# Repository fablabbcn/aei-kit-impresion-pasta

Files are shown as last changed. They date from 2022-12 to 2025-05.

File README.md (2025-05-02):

# CLAB Paste and Biomaterials Printing Kit



Welcome to the repository for the [AEI-CLAB](https://fablabbcn.org/projects/clab) project. This deliverable from [Fab Lab Barcelona](https://fablabbcn.org/) contains the design files, assembly guides, schematics, and the Bill of Materials (BOM) required to modify a Creality Ender3 or similar FDM 3D printer into a paste extrusion system.

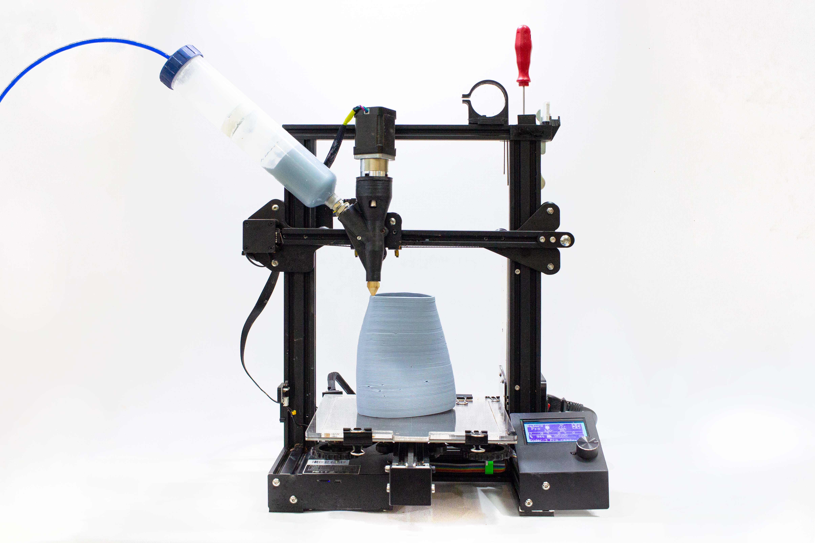
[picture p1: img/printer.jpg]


**Key Features:**

* Air pressure feed for extrusion: safer, easier to configure, and cleaner.
* Minimal hardware: only 4 screws needed for full disassembly, simplifying cleaning.
* Industrial-grade HDPE pressurised cartridges (200–300 cc), rated up to 6.9 bar (typical working pressure: 3–4 bar).
* Custom stainless-steel extruder screws with anti-corrosion plating.
* Silent air compressor (\~55 dB), 6 bar range, 3L tank with regulation and safety release valves.
  
## 3D-Printed Version

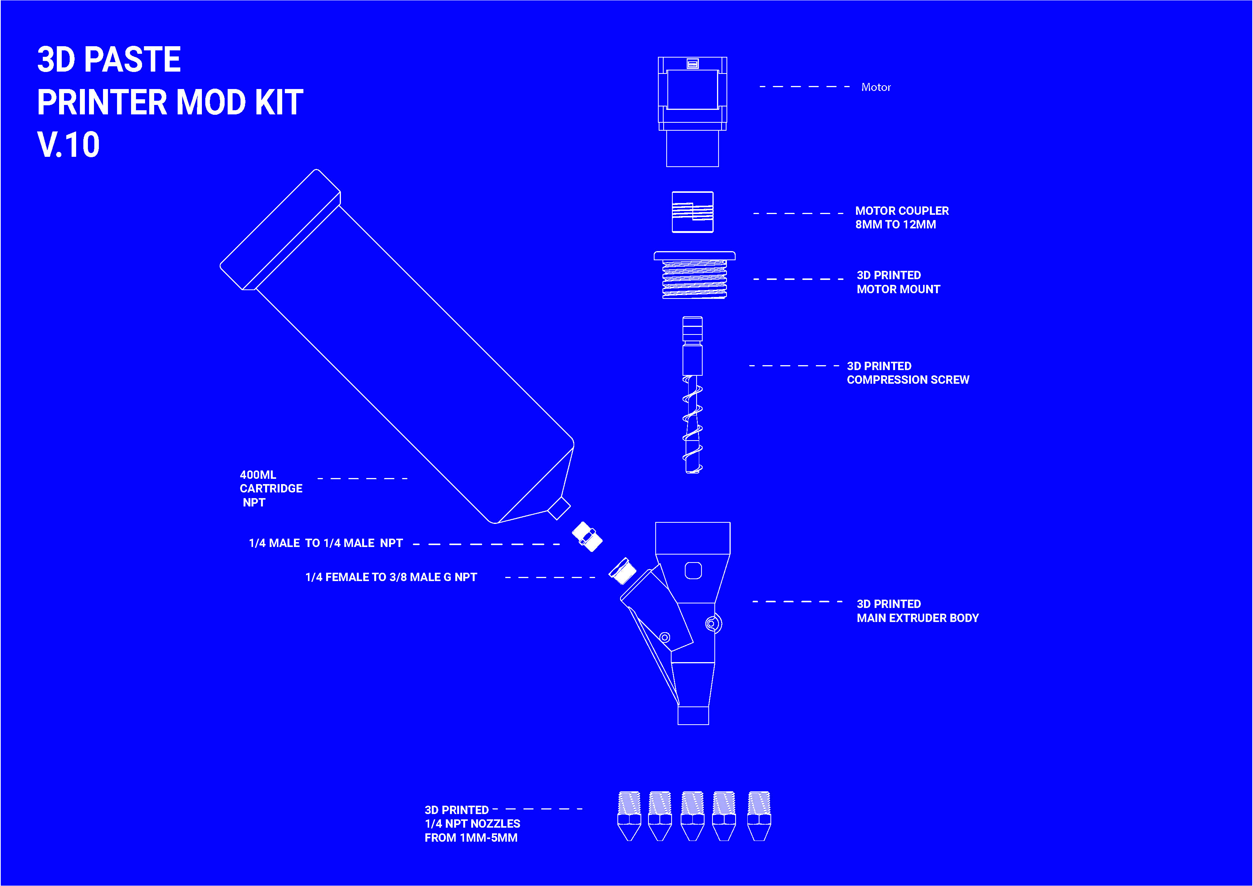
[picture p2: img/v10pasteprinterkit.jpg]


* All parts fit within a 200 x 200 x 200 mm standard FDM 3D printer.
* Minimal use of supports.
* Maximum print time: 12 hours (0.3 mm layer height).
* Less than 1 kg of filament required.

## Quick tutorial

👀 Follow along in these video tutorial shows you the ins and outs of safely and effectively using the 3D Printing Machine with #biomaterials and #paste.

[](https://www.youtube.com/watch?v=jNF1NYnVeio)

📺 https://www.youtube.com/watch?v=jNF1NYnVeio

## Kit Assembly

### Video tutorial

[](https://www.youtube.com/watch?v=v1bxhi_dhr8)

📺 https://www.youtube.com/watch?v=v1bxhi_dhr8

### Pictures

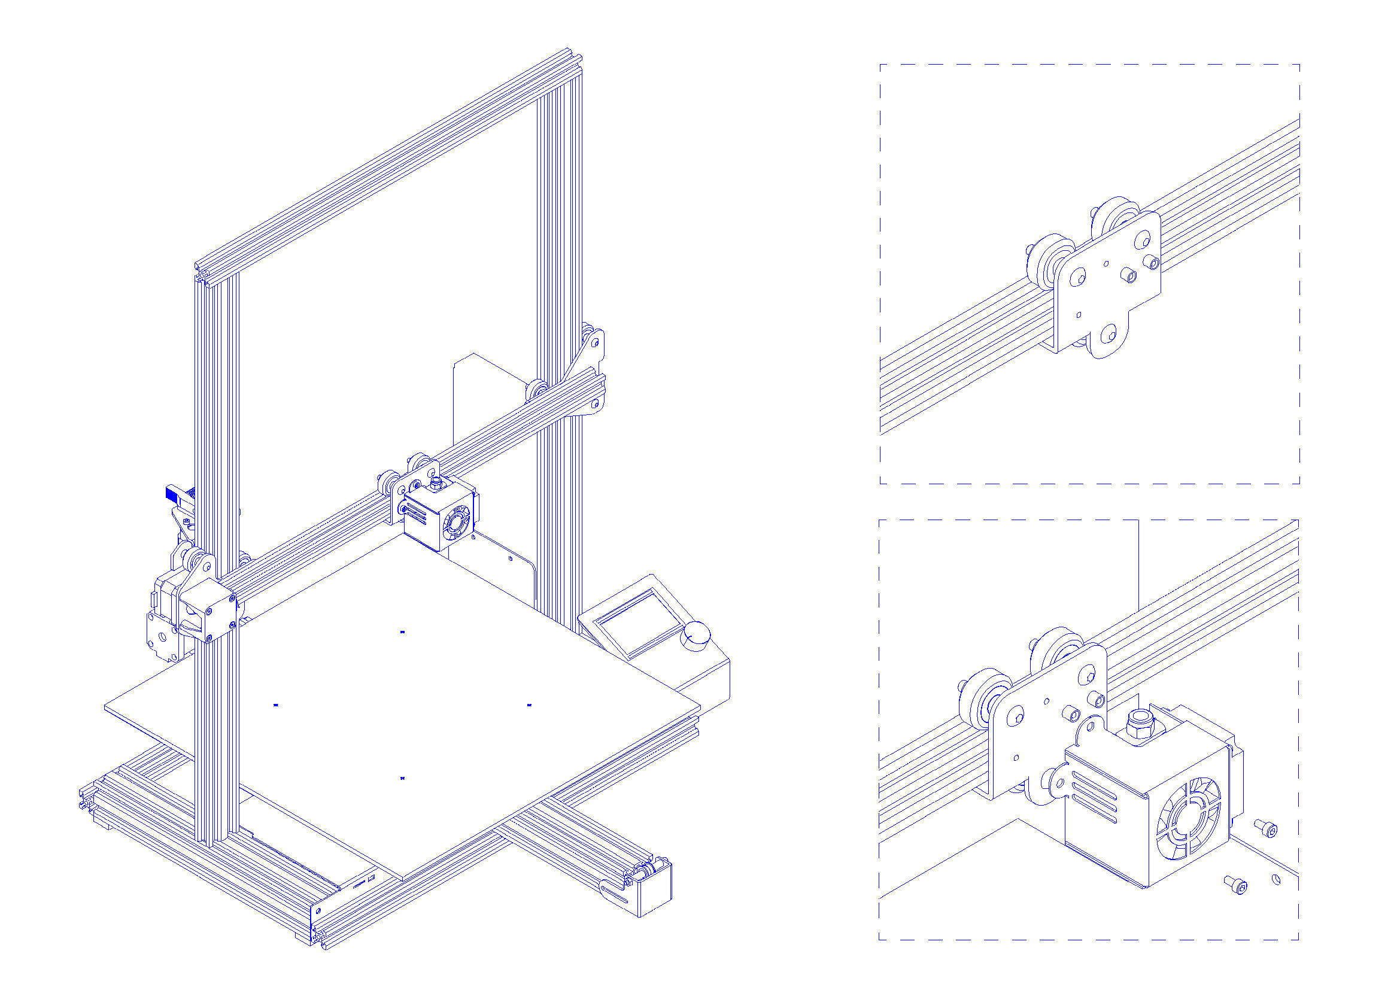
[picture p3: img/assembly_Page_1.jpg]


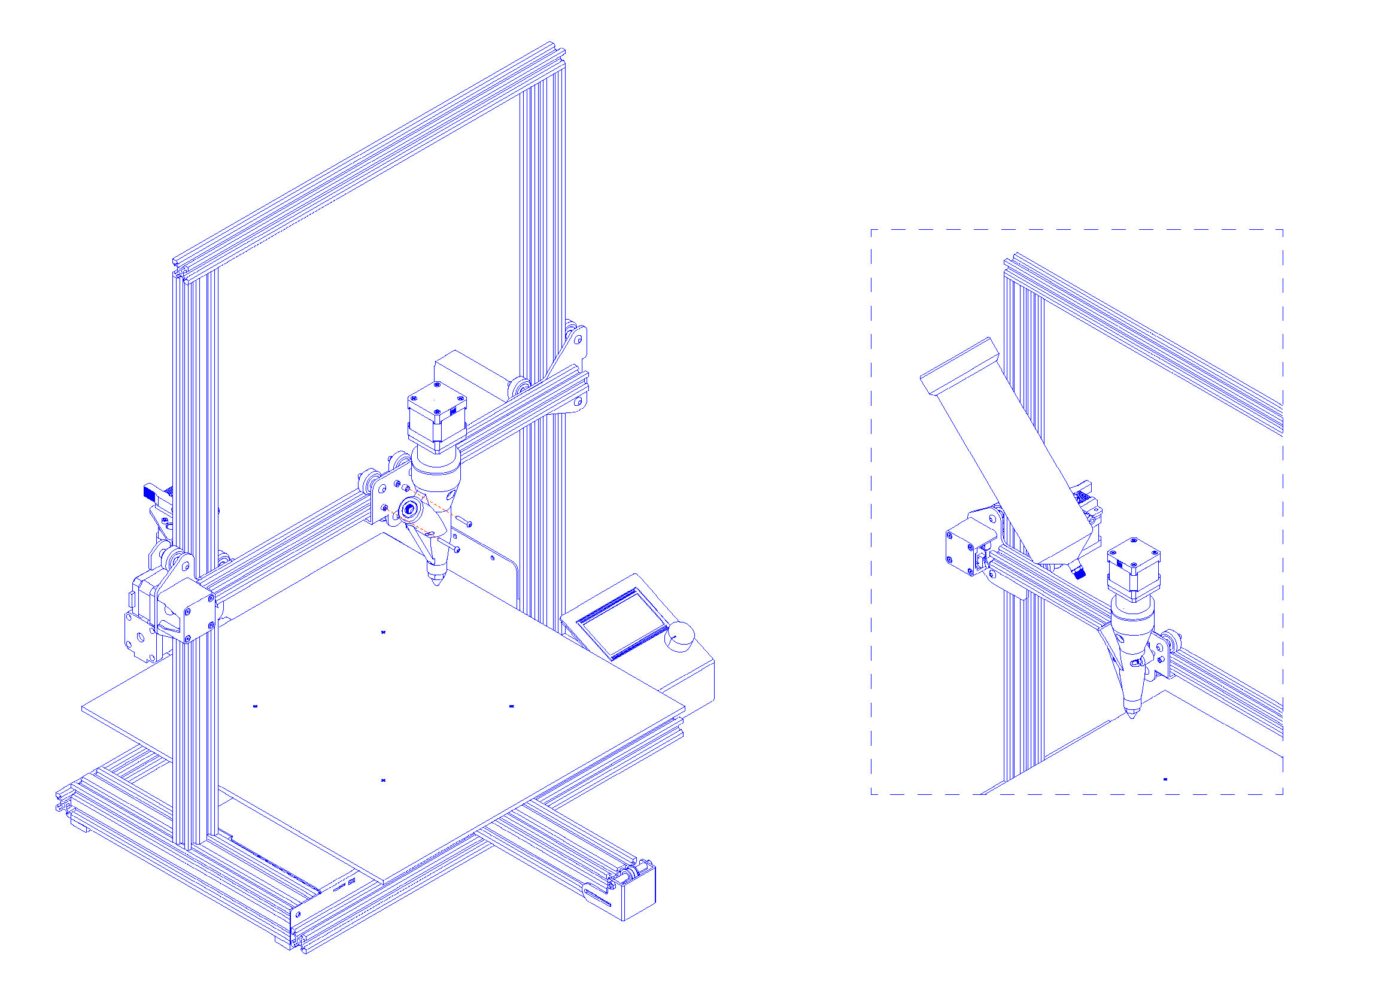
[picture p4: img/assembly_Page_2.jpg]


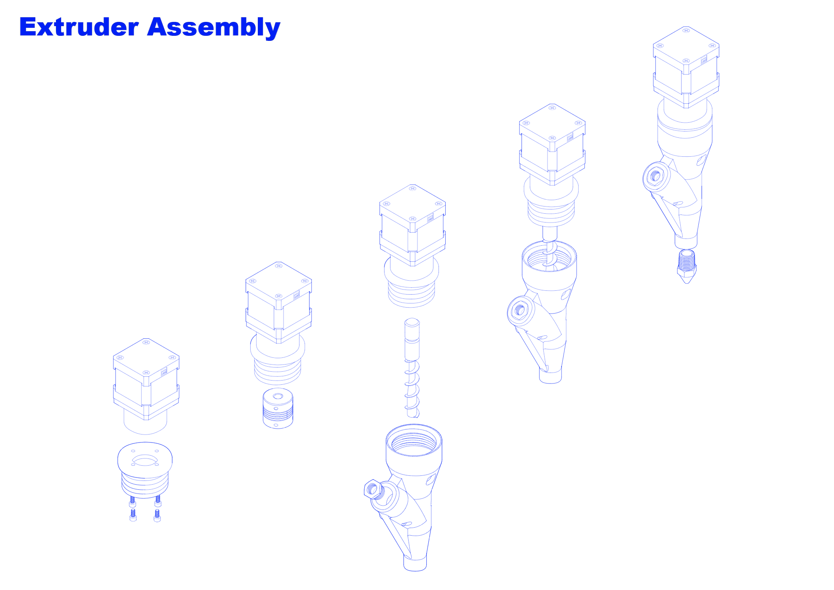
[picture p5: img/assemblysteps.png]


## Bill of Materials (BOM)



Download the complete [BOM in XLSX format](B.O.M.-PastePrintingPublicVersion.xlsx).

## Electronics Setup

If you disconnect the original FDM print head, place a 100k ohm resistor where the thermistor (temperature sensor) was connected.

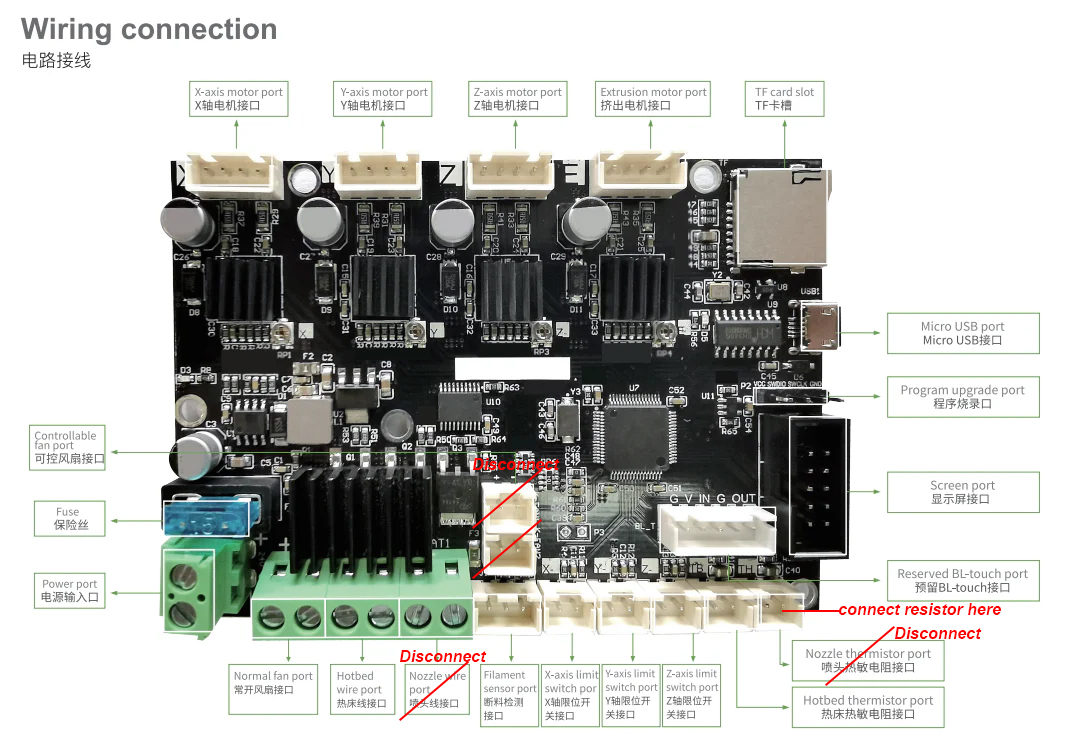
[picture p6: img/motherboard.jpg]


## About AEI-CLAB

The AEI-CLAB project promotes the use of maker technologies and 3D printing in education, focusing on sustainable, biocompatible materials like biomaterial pastes.

By integrating 3D printing into education, students develop technical and creative skills and gain hands-on scientific and technological understanding. The use of biomaterials fosters sustainable and innovative solutions.

The project offers workshops and activities for secondary and university-level students, combining digital design with biomaterials printing to boost creativity, innovation, and environmental awareness.

## Repository Contents

This repository includes:

* [3D printable files](3DPrintingFiles)
* Assembly images and schematics
* [Bill of Materials (BOM)](B.O.M.-PastePrintingPublicVersion.xlsx)

## Downloads

All files are available in this repository.

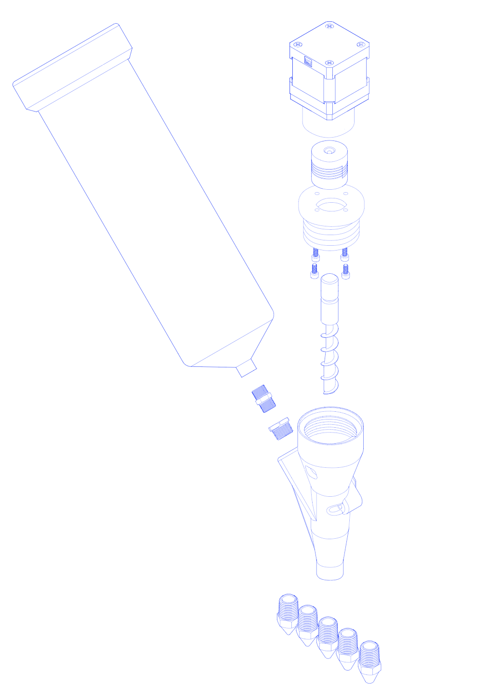
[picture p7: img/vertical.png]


## Extras

Before printing, we recommend checking your files using a G-code viewer.

Try this minimalist [G-code Web Visualizer](https://fablabbcn-projects.gitlab.io/cnc-machines/g-code-visualizer/).

## Credits

Project developed by Eduardo Chamorro Martin for Fab Lab Barcelona at IAAC (Institute for Advanced Architecture of Catalonia) under the 2022 call for Innovative Business Cluster Support by the Ministry of Industry, Commerce and Tourism.

Project title: **CLAB: Innovation in Circular and Open Manufacturing Processes for Educational Environments**

**Partners:**

* IAAC & Fab Lab Barcelona
* Fundación Bofill
* Kid's Cluster
* Abacus Cooperativa
* Esteam Education
* Anthesis Lavola

## Special Thanks

* Santi Fuentemilla & Guillem Camprodon for coordination and support.
* Ashkan Foroughi Dehnavi for construction and testing.
* Josep Martí for helping test multiple iterations.
* Daphne Gerodimou for extensive documentation work and visuals.

## Contributions

We welcome contributions! Feel free to fork the repository and submit pull requests with improvements or new features.

## License

Hardware: [CERN Open Hardware Licence v1.2](LICENSE-hardware)
Software: [GNU GPL v3.0](LICENSE-software)

---

**Spanish version:**

# CLAB Kit de Impresión en Pasta y Biomateriales



Bienvenido al repositorio del proyecto [AEI-CLAB](https://fablabbcn.org/projects/clab). Este entregable de Fab Lab Barcelona contiene los archivos de diseño, guías de montaje, esquemas y la Lista de Materiales (BOM) necesarios para modificar una impresora FDM tipo Creality Ender3 en un sistema de extrusión de pasta.



**Características principales:**

* Sistema de alimentación por presión de aire: más seguro, fácil de configurar y limpio.
* Poca tornillería: solo 4 tornillos necesarios para el desmontaje completo, facilitando la limpieza.
* Cartuchos presurizados de HDPE de grado industrial (200–300 cc) seguros hasta 6,9 bar (presión de trabajo típica: 3–4 bar).
* Tornillos extrusores personalizados en acero inoxidable con recubrimiento anticorrosión.
* Compresor silencioso (\~55 dB), rango de 6 bar, depósito de 3L con válvulas de regulación y seguridad.

## Versión Impresa en 3D



* Todas las piezas caben en una impresora 3D estándar de 200 x 200 x 200 mm.
* Uso mínimo de soportes.
* Tiempo máximo de impresión: 12 horas (altura de capa de 0,3 mm).
* Menos de 1 kg de filamento necesario.

## Tutorial rápido

👀 Sigue este vídeo tutorial para aprender, de forma segura y eficaz, a utilizar la máquina de impresión 3D con **biomateriales** y **pasta**.

[](https://www.youtube.com/watch?v=jNF1NYnVeio)

📺 https://www.youtube.com/watch?v=jNF1NYnVeio

## Montaje del KIT

### Video tutorial

[](https://www.youtube.com/watch?v=v1bxhi_dhr8)

📺 https://www.youtube.com/watch?v=v1bxhi_dhr8

### Fotos







## Lista de Materiales (BOM)



Descarga la [Lista de Materiales completa en formato XLSX](B.O.M.-PastePrintingPublicVersion.xlsx).

## Montaje Electrónico

Si desconectas el cabezal de impresión FDM original, debes colocar una resistencia de 100k ohmios donde estaba conectado el termistor (sensor de temperatura).



## Sobre AEI-CLAB

El proyecto AEI-CLAB promueve el uso de tecnologías maker y la impresión 3D en educación, enfocándose en materiales sostenibles y biocompatibles como las pastas de biomateriales.

La impresión 3D en entornos educativos permite a los estudiantes desarrollar habilidades técnicas y creativas, además de comprender conceptos científicos y tecnológicos de forma práctica. El uso de biomateriales impulsa soluciones innovadoras y responsables.

El proyecto ofrece talleres y actividades para estudiantes de nivel secundario y universitario, combinando el diseño digital con la impresión de biomateriales para fomentar la creatividad, la innovación y la conciencia ambiental.

## Contenidos del Repositorio

Este repositorio incluye:

* [Archivos imprimibles en 3D](3DPrintingFiles)
* Imágenes de montaje y esquemas
* [Lista de Materiales (BOM)](B.O.M.-PastePrintingPublicVersion.xlsx)

## Descargas

Todos los archivos están disponibles en este repositorio.



## Extras

Antes de imprimir, te recomendamos visualizar tus archivos G-code.

Puedes usar esta versión minimalista del [Visualizador Web de G-code](https://fablabbcn-projects.gitlab.io/cnc-machines/g-code-visualizer/).

## Créditos

Proyecto desarrollado por Eduardo Chamorro Martin para Fab Lab Barcelona en el IAAC (Instituto de Arquitectura Avanzada de Cataluña) en el marco de la convocatoria 2022 de ayudas a Agrupaciones Empresariales Innovadoras del Ministerio de Industria, Comercio y Turismo.

Título del proyecto: **CLAB: Innovación en Procesos de Fabricación Circular y Abierta para Entornos Educativos**

**Partners:**

* IAAC & Fab Lab Barcelona
* Fundación Bofill
* Kid's Cluster
* Abacus Cooperativa
* Esteam Education
* Anthesis Lavola

## Agradecimientos

* Santi Fuentemilla & Guillem Camprodon por la coordinación y apoyo del proyecto.
* Ashkan Foroughi Dehnavi por el trabajo de construcción y pruebas.
* Josep Martí por ayudar a probar varias versiones.
* Daphne Gerodimou por el extenso trabajo de documentación y visuales.

## Contribuciones

¡Te animamos a contribuir! Puedes bifurcar el repositorio y enviar pull requests con mejoras o nuevas funcionalidades.

## Licencia

Hardware: [CERN Open Hardware Licence v1.2](LICENSE-hardware)
Software: [GNU GPL v3.0](LICENSE-software)

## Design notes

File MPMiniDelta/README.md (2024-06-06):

## What is this for?

This is a design variation of the nozzle assembly to fit the Monoprice Mini Delta 3D printer. It is based on the same principles as the main design in the main repository. However, due to the lack of space, I used a push-in fitting method to connect the air piston with the nozzle.

## What are the different parts

I used a pallet screw of 8mm shaft diameter, found on Aliexpress: https://www.aliexpress.com/item/32984182099.html?spm=a2g0o.order_list.order_list_main.29.603f18022yR21D



And a push-in fitting size of 1/4 BSP standard



## Assembly
ezgif com-resize

20230916_104944 (2)

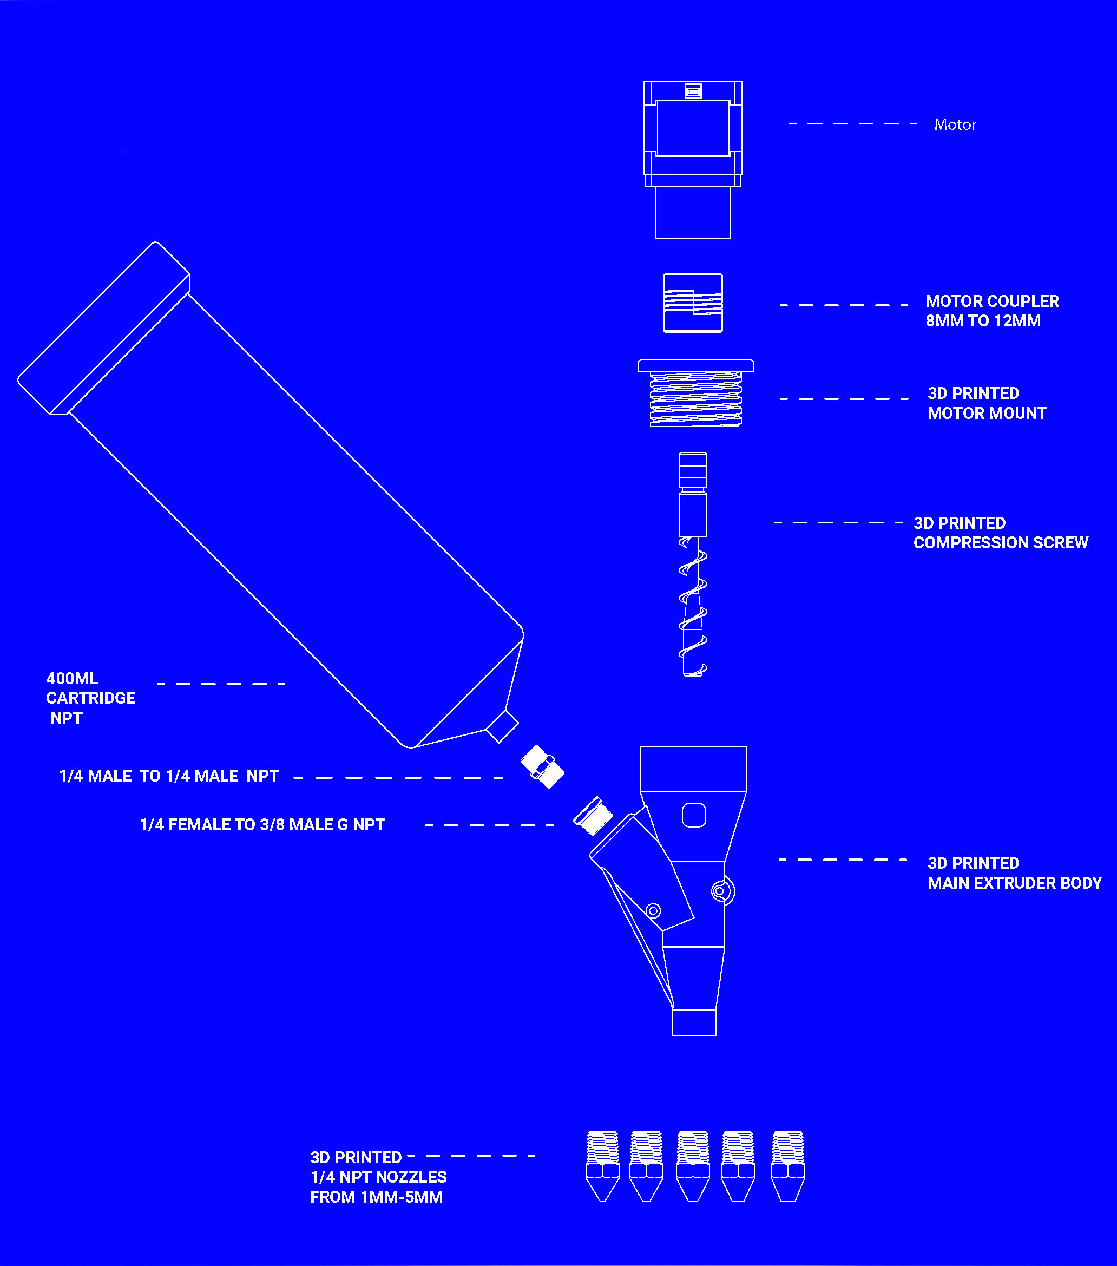
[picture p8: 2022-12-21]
img/v10pasteprinterkitslim.jpg

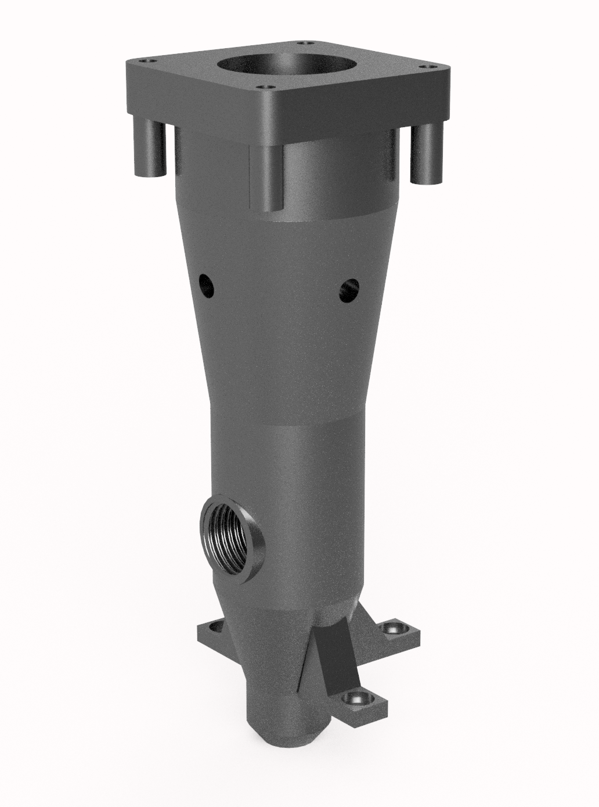
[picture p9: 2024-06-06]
MPMiniDelta/pic.png

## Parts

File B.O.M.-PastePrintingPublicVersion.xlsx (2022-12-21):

Commentario | Componente | Nombre | Material | Proveedor | Link de referencia | notas/links alternativos | Unidades en el pack | Unidades necesarias por kit | Precio unitario | Precio total por kit
Lista de materiales para producir un kit de impresion en pasta/biomateriales
 | Impresora | Creality3D Ender-3 or ender 5 | metal,plastico,cobre | creality shop | https://www.creality3dshop.eu/collections/ender-series-3d-printer/products/creality3d-ender-5-pro-3d-printer |  | 1 | 2 | 209.99 | 419.98
 | Compresor aire max 6 bar | Compresor de aerógrafo Fengda FD-186 con calderín / ORIGINAL FENGDA / regulador de presión / 3L / 4 bar / parada automática | metal,plastico,cobre | amazon | https://www.eltallerdelmodelista.com/es/compresor-de-doble-piston-y-calderin-p-33280.html | https://www.amazon.es/Compresor-aer%C3%B3grafo-Fengda-regulador-autom%C3%A1tica/dp/B019CKXHDK | 1 | 1 | 154.78€ | 154.78€
 | Material de impresión en 3d filamento | Filament PLA | PLA plastico | smartmaterials | https://www.smartmaterials3d.com/pla-filamento |  | 1 | 1 | 19.95 | 19.95
 | Pegamento epoxy |  | Epoxy | AMAZON | https://www.amazon.com/-/es/4200130-Gorilla-Epoxy-4200101-2/dp/B01M7VD07W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 |  | 2 | 1 | 14 | 7
 | 6 to 6 open/close valve | valve to close air compressor flow | Polipropileno | rs | https://es.rs-online.com/web/p/valvulas-neumaticas-de-accionamiento-manual/9160968 | packs of 10, unit price | 10 | 1 | 3.62 | 0.362
 | Pneumatic pressure piper 6mm that connects to the compressor |  | Polipropileno | rs | https://es.rs-online.com/web/p/mangueras-y-tubos-flexibles/2337311 |  | 20 | 1 | 13.11 | 0.6555
 | Piezas del kit | KIT DE PIEZAS IMPRIMIBLES EN 3D | PLA PLASTICO | IMPRESO EN 3D |  |  | 1 | 1 | 0 | 0
 | Motor paso a paso con reductora | Nema 17 Stepper Motor Bipolar L=48mm w/ Gear Ratio 5:1 Planetary Gearbox | Acero,cobre,plastico abs | omc-stepperonline | https://www.omc-stepperonline.com/nema-17-stepper-motor-bipolar-l-48mm-w-gear-ratio-5-1-planetary-gearbox-17hs19-1684s-pg5 |  | 1 | 1 | 32.8 | 32.8
 | Acople motor | 8 to 12mm | Aluminio | amazon | https://www.amazon.es/sourcingmap%C2%AE-Aleaci%C3%B3n-aluminio-helicoidal-acoplamiento/dp/B06X99YZ34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 |  | 1 | 1 | 9.99 | 9.99
 | 300 CC Cartucho 1/4 NPT Rosca | 300cc Clear Syringe Barrel Assembly Kit AD300XL |  | china | https://es.aliexpress.com/item/1005003632721391.html | https://es.aliexpress.com/item/1005001928697782.html?scm_id=1007.13338.177931.0&scm-url=1007.13338.177931.0 | 2 | 2 | 10 | 10
 | 6mm to 6mm conector pneumatico | Encaje a presión, 6 mm, con. B Encaje a presión, 6 mm | Plastico polipropileno | rsonline | https://es.rs-online.com/web/p/racores-neumaticos/9160873 | packs of 10 | 10 | 1 | 12.95 | 1.295
 | Hembra G 1/4, con. B Encaje a presión, 6 mm | Compressor conector to 6mmpipe | Acero | rsonline | https://es.rs-online.com/web/p/racores-neumaticos/1216160 | packs of 10 | 10 | 1 | 40.44 | 4.044
 | 1/4 hembra to 3/8 macho NPT conector | Macho G 3/8, con. B Hembra G 1/4 | Acero | rsonline | https://es.rs-online.com/web/p/racores-neumaticos/2180121 | packs of 10 | 10 | 1 | 12.12 | 1.212
 | 1/4 macho to 1/4 macho NPT conector | Adaptador de rosca recto, con. A Macho G 1/4, con. B Macho G 1/4 | Acero | rsonline | https://es.rs-online.com/web/p/racores-neumaticos/3675534 | packs of 5 | 5 | 1 | 6.78 | 1.356
 | Inserto metálico, M3, 5.5mm |  | Latón | rsonline | https://es.rs-online.com/web/p/insertos-roscados/2040620 | pack of 100 | 100 | 6 | 30.76 | 1.8456
 | 3mm tornillo métrico 30mm longitud | Tornillo Allen, Acero Inoxidable, Cabezal con Casquillo Hexagonal, M3 x 30mm 0.5mm | Acero | rsonline | https://es.rs-online.com/web/p/tornillos-allen/0293331 | pack of 50 | 50 | 2 | 27.11 | 1.0844
 | 3mm tornillo métrico 20mm longitud (for body mount) | Tornillo Allen, Acero Inoxidable, Cabezal con Casquillo Hexagonal, M3 x 20mm 0.5mm | Acero | rsonline | https://es.rs-online.com/web/p/tornillos-allen/0293319 | pack of 50 | 50 | 8 | 19.49 | 3.1184
 | 3mm tornillo métrico 8mm longitud (for motor &platemount) | Tornillo Allen, Acero Inoxidable, Cabezal con Casquillo Hexagonal, M3 x 8mm 0.5mm | Acero | rsonline | https://es.rs-online.com/web/p/tornillos-allen/0280997 | pack of 50 | 50 | 8 | 19.99 | 3.1984
 | XH female connector extender | extender for stepper | Plastico silicona y aluminio | china | https://es.aliexpress.com/item/4000119140643.html?_t=pvid%3A20f241c8-1c58-4814-af13-98ccce74660c | 1 | 1 | 1 | 2.1 | 2.1
 | Resistencia electronica 1/2W 5% 10M | resistor for fake temperature | Ceramico | rsonline | https://es.rs-online.com/web/p/resistencias-de-montaje-en-orificio-pasante/1995028 | packs of 10 | 10 | 1 | 3.45 | 0.345
 | Conector JST XH 2 Pin Female de 2.54mmwith cable | connector and cable for resistor | Plastico abs y aluminio | polulu | https://www.pololu.com/product/1164 | 1 | 1 | 1 | 1.15 | 1.15
 | Tornillo impreso en 3d en Acero inoxidable diseño customizado | Stainless Steel 17-4PH (BJT) | acero inoxidable | shapeways | https://www.shapeways.com/ |  | 1 | 1 | 67.7 | 40

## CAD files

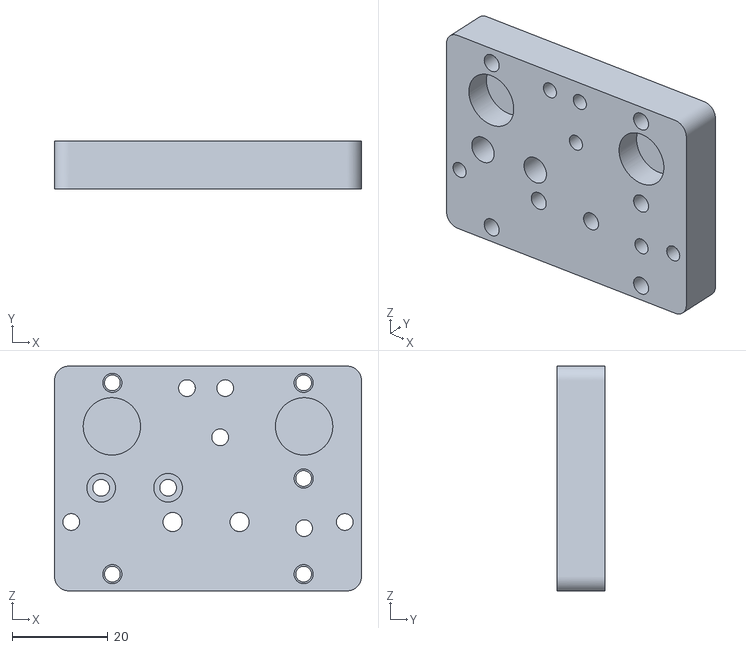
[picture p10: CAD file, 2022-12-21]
3DPrintingFiles/AdaptorEnder1.stl
64.2 x 10.0 x 47.0

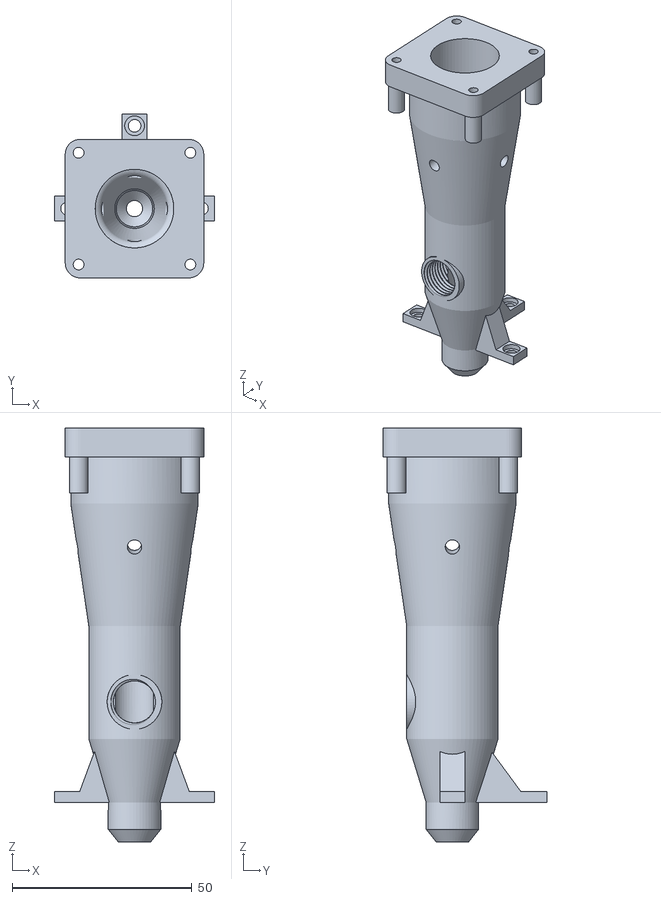
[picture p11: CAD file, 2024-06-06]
MPMiniDelta/Nozzle.stl
44.5 x 45.5 x 115.0

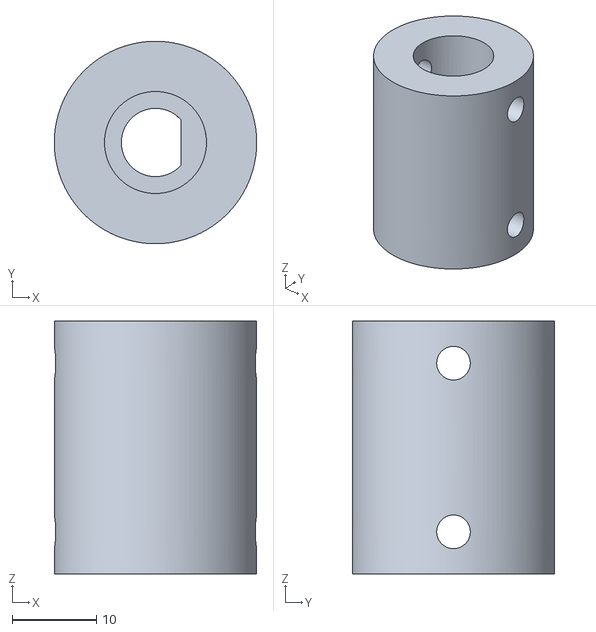
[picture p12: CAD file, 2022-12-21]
3DPrintingFiles/Coupler8To12.stl
24.0 x 24.0 x 30.0

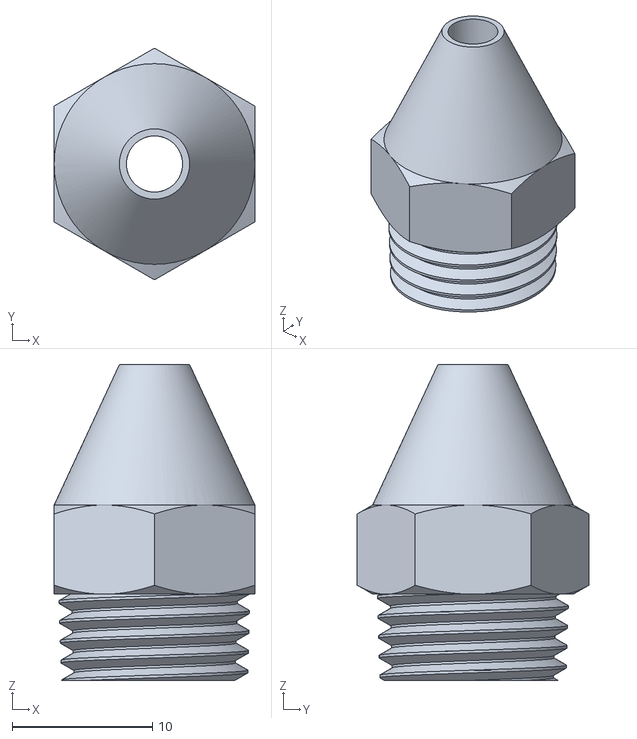
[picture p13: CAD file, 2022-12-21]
3DPrintingFiles/ShortNoozle4mm.stl
14.3 x 16.5 x 22.5

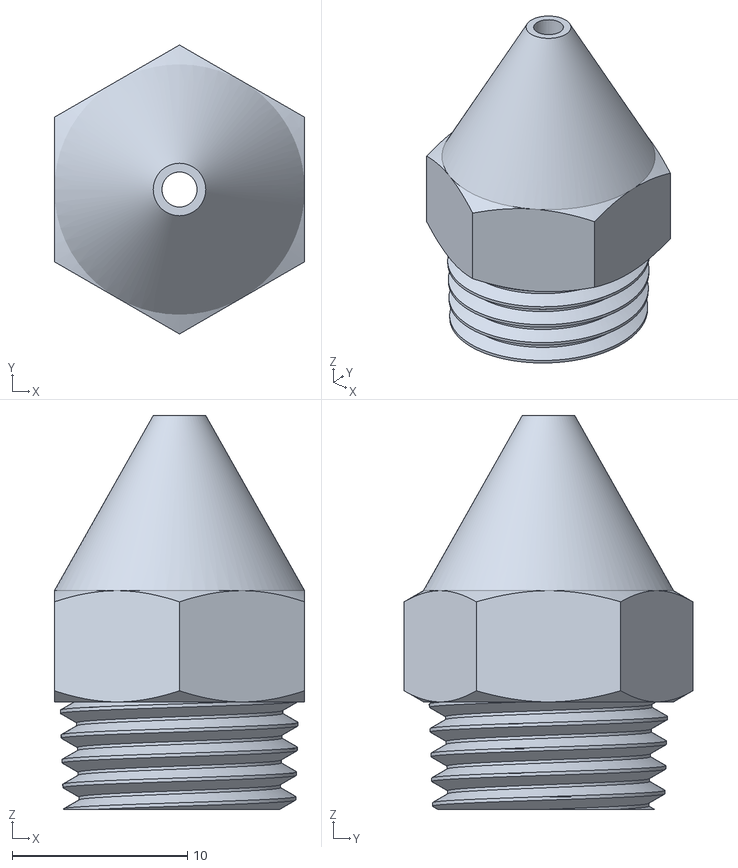
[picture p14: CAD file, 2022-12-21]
3DPrintingFiles/ShortNoozle2mm.stl
14.3 x 16.5 x 22.5

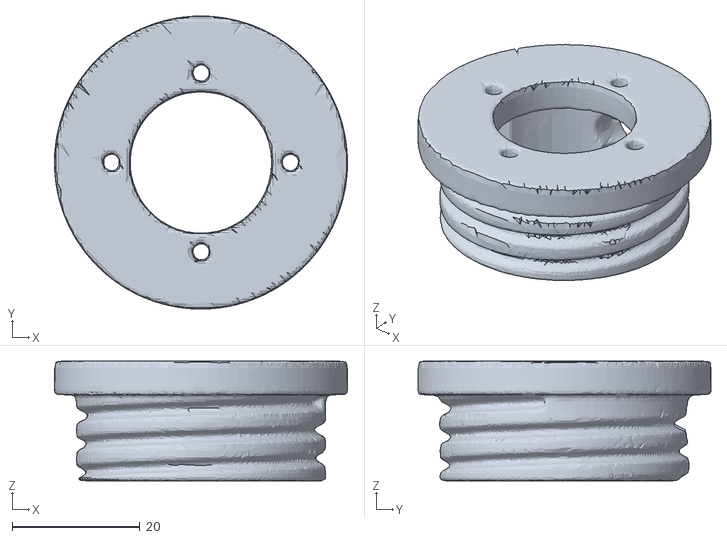
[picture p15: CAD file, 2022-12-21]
3DPrintingFiles/MountReductionMotor.stl
45.9 x 45.9 x 18.7

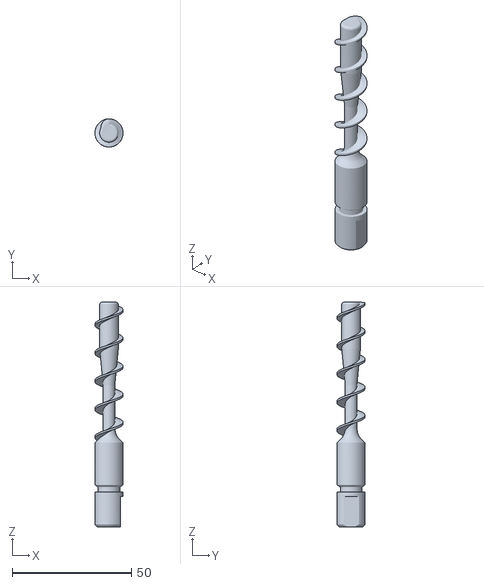
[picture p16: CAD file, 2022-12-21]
3DPrintingFiles/PastePrintingScrew.stl
11.8 x 11.8 x 94.2

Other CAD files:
3DPrintingFiles/ShortNoozle5mm.stl
3DPrintingFiles/ShortNoozle3mm.stl
3DPrintingFiles/ShortNoozle1mm.stl

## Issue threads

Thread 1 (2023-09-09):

Design variation for MP delta mini V1

abinmahfuth, 2023-09-09:
Hi all,

Many thanks for the inspiring design. I have the MP delta mini V1 and made a new nozzle design to fit that printer, I hope if you share more people will benefit. More details about the assembly will follow.

You can find it here:
https://github.com/abinmahfuth/aei-kit-impression-paste-MP-Delta

oscgonfer, 2023-09-21:
Hi @abinmahfuth

Nice! Do you want to maybe [create a Pull Request on the repo](https://github.com/fablabbcn/aei-kit-impresion-pasta/compare)?

abinmahfuth, 2023-10-01:
Hi @oscgonfer,

Thanks for your response, I just did create a Pull request :)

Closed 2023-10-06.

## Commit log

2022-12-21 bom publica
    [B.O.M.-PastePrintingPublicVersion.xlsx]
2022-12-21 3d parts
    [MountReductionMotor.stl, PastePrintingScrew.stl, ShortNoozle1mm.stl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]
2022-12-21 noozle push
    [ShortNoozle4mm.stl, ShortNoozle5mm.stl]
2022-12-21 files added
    [Coupler8To12.stl]
2022-12-21 adaptor push
    [AdaptorEnder1.stl]
2022-12-21 motor mount
2023-09-29 Added 3D printing files
    [Nozzle.stl]
